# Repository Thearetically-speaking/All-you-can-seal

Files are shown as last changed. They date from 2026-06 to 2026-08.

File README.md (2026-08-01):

# All You Can SEAL

> Modify Bambu Lab 3D printers into a TPU heat-sealing tool by patching G-code.

This project rewrites the G-code inside Bambu Studio's `.gcode` and `.gcode.3mf` files to repurpose any Bambu printer (tested on **A1 mini** and **P1S**) as a heat-sealing machine. Instead of extruding filament to build a 3D object, the modified printer traces a 2D path with the nozzle hovering just above the bed — fusing two layers of TPU film into a custom-shaped inflatable pouch.

## What it does
 
Soft pneumatic wearables need airtight TPU chambers, and making them has traditionally required an impulse sealer, an ultrasonic welder, or a custom CNC sealing platform. This method produces them on a stock consumer 3D printer.
 
Heat sealing needs three inputs — **heat, contact pressure, and dwell time**. All three are recovered from parameters the printer already has:
 
| Input | How it's delivered |
|---|---|
| **Heat** | Raised nozzle temperature |
| **Pressure** | A negative Z offset presses the nozzle into the film stack, with the force distributed by a bead of over-extruded molten TPU |
| **Dwell time** | A heavily reduced feed rate |
 
**Extrusion stays on — that's the point.** Prior 3D-printer sealing methods disable extrusion and use the bare nozzle as a passive heat source, which lets residue build up and wears the nozzle. Here the deposited bead acts as a continuously refreshed interface between nozzle and film: it transmits heat and pressure into the stack while lubricating the nozzle so it doesn't drag on the release layer. The bead is part of the mechanism, not a by-product.
 
Nothing is modified or sacrificed. Only the parchment release layer is consumed per seal, and the printer goes back to normal printing immediately afterwards.
 
---
 
## Two ways to use it
 
### 🛜 Web app (recommended)
 
<https://thearetically-speaking.github.io/All-you-can-seal/>
 
1. **Convert** — drop in a `.gcode.3mf` exported by Bambu Studio (or a bare `.gcode`), pick your film thickness, download the patched file.
2. **Validate** — check a patched file before you send it to the printer. Worth doing every time; this workflow drives the nozzle *below* the bed's zero point.
Available in English and 中文. All processing happens client-side.
 
### 🐍 Python script
 
```bash
git clone https://github.com/Thearetically-speaking/All-you-can-seal.git
cd All-you-can-seal
python3 allyoucanseal-bambu.py path/to/your_sliced_file.gcode.3mf
```
 
Python 3.10+, standard library only. The script edits the file in place and writes two copies alongside it for diffing:
 
```
your_file.before.gcode    # original
your_file.after.gcode     # patched
your_file.gcode.3mf       # patched, ready to send
```
 
It works by treating the `.gcode.3mf` as the ZIP archive it is, locating `Metadata/plate_1.gcode`, patching both the config header and the machine body, and repacking.
 
---
 
## Parameters
 
**Verified on 0.03 mm and 0.05 mm TPU film**, across the **A1 mini**, **A1**, and **P1S**. For each thickness a single parameter set transfers across all three printers with no per-device tuning. Everything below is measured, not extrapolated — see [Other films](#other-films) for what is and isn't expected to carry over.
 
| Parameter | Stock | 0.03 mm film | 0.05 mm film | Role |
|---|---|---|---|---|
| Nozzle temperature | 230 °C | **250 °C** | **260 °C** | Heat |
| Z offset | 0 mm | −0.10 mm | −0.15 mm | Pressure |
| Extrusion multiplier | 100 % | 120 % | 120 % | Bead |
| Feed rate | 30 000 mm/min | **300 mm/min** | **180 mm/min** | Dwell |
 
Only the two thermal parameters change with thickness — heat delivery has to scale with the film's thermal mass. The pressure parameters hold constant across the tested range.
 
**Minimum reliable seam width: 2 mm**, at both thicknesses. Below that (tested at 1 mm) seals show occasional unbonded segments. The limit appears to be set by nozzle diameter and bead width rather than by the film.
 
---
 
## Other films
 
**The workflow is material-agnostic. The parameters are not.**
 
The stack-up, the slicer integration, and the patching script make no assumptions about what's being sealed — they only control heat, pressure and dwell. Any thin thermoplastic film that can be heat-sealed should be sealable this way. What has to be re-found for a new material is the *values*.
 
Splitting the four parameters by how far they're expected to travel:
 
| | Expected to transfer | Why |
|---|---|---|
| **Z offset**, **extrusion multiplier** | Likely, within a similar thickness range | These deliver mechanical contact pressure, and they held constant across our two thicknesses — the mechanism looks thickness-independent in the tested range |
| **Nozzle temperature**, **feed rate** | **No — must be re-tuned** | These deliver heat, which has to scale with the melting point and thermal mass of the specific film |
 
So a reasonable starting point for a new material: keep Z offset and extrusion multiplier, and search temperature and feed rate. Change one at a time. Prior work characterizing household thermoplastic films on stock FDM printers ([Therms-Up!](https://doi.org/10.1145/3430524.3442457)) is a useful reference for where different materials sit.
 
PVC and EVA are the obvious next candidates and are named as future work in the paper — **but read the safety note on PVC below before you try it.**
 
If you characterize a film we haven't, please open an issue with your parameters, film thickness and printer. A community-contributed table mapping film properties to parameter values is exactly what this needs.
 
---
 
## Hardware and materials
 
| Item | Notes |
|---|---|
| **Bambu Lab printer** | Verified on A1 mini, A1, P1S. Other Bambu models sharing the same G-code structure should work but are untested |
| **TPU film** | The material being sealed. Two layers. Characterized at 0.03 mm and 0.05 mm. Other thermoplastic films should work with re-tuned thermal parameters — see [Other films](#other-films) |
| **TPU filament** | Supplies the sealing bead. Generic Bambu TPU works |
| **Silicone mat, 2–3 mm** | Sits on the build plate. Absorbs the vertical contact force so the heated bed isn't indented and the nozzle never meets a rigid surface. **Not optional, and don't substitute cardboard** at these temperatures |
| **Parchment paper** | Release layer over the top of the stack. The bead adheres to the parchment, not to your film |
| **High-temperature tape** | Holds the stack at its edges. Kapton or equivalent — ordinary packing tape will not survive a 260 °C nozzle passing over it |
| **Spray bottle of water** | For misting between film layers |
 
---
 
## Material stack-up
 
Bottom to top:
 
1. Standard build plate
2. **2–3 mm silicone mat**
3. **Lower TPU film**, lightly misted with water — surface tension pulls it flat against the mat and eliminates trapped bubbles
4. **Upper TPU film**, again misted against the lower film so no air pocket remains between the two
5. **Parchment paper** covering the top, as the release layer
Tape the edges down with high-temperature tape so nothing shifts under nozzle motion.
 
The water misting is a functional step, not a nicety — trapped air between the layers produces unsealed segments.
 
---
 
## Full workflow
 
1. **Draw the seal path.** A closed 2D vector path (SVG). Keep the stroke ≥ 2 mm. Avoid sharp corners — the nozzle decelerates at corners and can scorch the film.
2. **Extrude to 0.28 mm** in Fusion 360 or any CAD tool, export STL. The 0.28 mm matches Bambu Studio's *Extra Draft* layer-height preset for a 0.4 mm nozzle, so the slicer emits exactly one layer of toolpath.
3. **Slice in Bambu Studio:** layer height 0.28 mm (Extra Draft), 1 layer, 1 wall, 100 % infill, no support, no brim. TPU filament profile, **bed temperature 30 °C**, **part cooling fan off** — active cooling stops the bead delivering sustained heat. Export as a **single-plate** slice file.
4. **Patch** with the web app or the script.
5. **Validate**, then dry-run with the heater off and watch the toolhead path before committing film.
6. **Seal.** Watch it.
---
 
## ⚠️ Safety
 
The printer is not permanently modified, but the process bypasses the slicer's safety checks. Read this before your first run.
 
- **The negative Z offset presses the nozzle below the bed's zero point.** Without the silicone mat you can scratch the build plate, damage the nozzle, or jam the toolhead.
- **250–260 °C is above the rated temperature of many TPU filaments.** Ventilate. Do not breathe the fumes.
- **Do not seal PVC or other chlorinated films without proper extraction.** PVC decomposes well below these temperatures and releases hydrogen chloride — corrosive to your lungs and to the printer. Room ventilation is not sufficient. This applies to any chlorine-containing film, including cling film and much craft vinyl. If you're exploring new materials, check the decomposition temperature and decomposition products *before* the melting point.
- **At 180–300 mm/min with the heater on, the nozzle dwells over every point.** Do not leave the printer unattended — if the toolhead stalls, the stack scorches within seconds.
- **Always dry-run first** with the heater off.
- Not endorsed by Bambu Lab. May void your warranty.
Intended for researchers, makers, and educators experimenting with soft fabrication. Not a product.
 
---
 
## Troubleshooting
 
**"Metadata/plate_1.gcode not found."** Your file was exported as multi-plate. In Bambu Studio use *Export single-plate slice file*.
 
**"CONFIG_BLOCK_END / MACHINE_START_GCODE_END not found."** The file wasn't sliced by Bambu Studio against a Bambu printer profile. Re-slice.
 
**Seal peels apart after cooling.** Not enough heat into the stack: raise temperature ~5 °C, or lower the feed rate. Change one variable at a time.
 
**Film scorches or browns.** Too much heat: drop the temperature first, then raise the Z offset toward zero. Confirm the parchment is between nozzle and film.
 
**Unsealed gaps along the path.** Seam width below 2 mm, trapped air between layers (mist more), or the stack shifted (more tape).
 
**Nozzle scrapes the bed.** Z offset too aggressive for your stack, or the silicone mat is too thin. Try −0.05 mm.
 
**Non-Bambu printer?** Not directly — the script targets Bambu's G-code dialect and the `.3mf` layout. Adapting it for Prusa or Klipper is feasible but unimplemented.
 
---
 
## Repository contents
 
| File | |
|---|---|
| `allyoucanseal-bambu.py` | The patching script |
| `test1.gcode.3mf` | Sample sliced file for testing the workflow |
| `TPU_Inflatable.pdf` | Reference seal patterns |
 
---
 
## Project context
 
Developed for **Catlike**, a Research-through-Design thesis on emotion-responsive pneumatic wearables at OCAD University — an HRV-responsive headpiece and a plantar-pressure-responsive shoe, both built on TPU bladders sealed in custom shapes.
 
The sealing method went through four stages: soldering iron → hair straightener → Cricut heat press → Bambu printer. Structures made with this workflow ran continuously in a four-day exhibition with no observed leakage.
 
If you use this for soft-robotics or wearable research, I'd like to hear about it.
 
## License
 
MIT.
 
You are free to share and adapt the material for non-commercial purposes, with attribution. Commercial use requires explicit permission.

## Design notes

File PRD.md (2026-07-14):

# PRD — All You Can Seal Web（网页版热封 G-code 处理器）

| | |
|---|---|
| 版本 | v0.1 草稿 |
| 日期 | 2026-07-12 |
| 现状 | 命令行脚本 `allyoucanseal-bambu.py`（Python，本地运行） |
| 目标形态 | 纯静态网页应用，托管于 GitHub Pages |

---

## 1. 背景与目标

现有的 Python 脚本可以把 Bambu Studio 切片产出的 `.gcode.3mf` 改写为 TPU 热封 G-code（改温度、Z 偏移、流量倍率、移动速度）。但它有明显的使用门槛和已知缺陷：

- 需要本地安装 Python，命令行操作，对非技术用户不友好；
- 改写结果不可见——用户无法在打印前直观确认路径和参数是否正确；
- 源打印温度 230°C 被硬编码，切片档位不是 230 时静默失败；
- 不更新 3mf 内的 `Metadata/plate_1.gcode.md5`，改写后校验和失效；
- 只支持单盘（`plate_1.gcode` 写死），多盘文件直接报错；
- 结构标记缺失时"改一半"而不是中止，可能产出危险的半成品文件。

**目标**：做一个零安装、拖拽即用的网页工具，覆盖并修复以上全部问题，让用户从"切片完成"到"拿到可打印的热封 3mf"在浏览器内一站完成，且在导出前能像切片软件一样预览整个热封路径。

**非目标（Out of Scope）**：
- 不做切片功能——用户仍需用 Bambu Studio 产出 `.gcode.3mf`；
- 不做非 Bambu 方言（Prusa/Klipper）的支持（架构上预留扩展点即可）;
- 不做打印机直连（LAN/云端发送）；
- 不做账号系统、云存储——文件全程只存在于用户浏览器内存中。

---

## 2. 用户与使用场景

**目标用户**：软体机器人 / 可穿戴研究者、maker、教育者。会用 Bambu Studio 切片，但不一定会命令行。

**核心使用流程（Happy Path）**：

1. 打开网页（GitHub Pages URL）；
2. 把 Bambu Studio 导出的 `.gcode.3mf` 拖进页面；
3. 网页自动解析：识别机型、检出切片温度、列出盘（plate）；
4. 用户在参数面板确认/调整四个热封参数（默认值即当前脚本常量）；
5. 3D 预览区显示改写后的完整路径，拖动 slider 逐步查看喷嘴行进过程；
6. 安全检查面板全绿（或用户确认警告）后，点击导出；
7. 浏览器下载改写后的 `.gcode.3mf`，用户发送到打印机。

---

## 3. 功能需求

### FR-1 文件导入（拖拽 + 点击选择）

- 支持拖拽（drag & drop）和点击文件选择两种方式；接受 `.gcode.3mf` 和裸 `.gcode`。
- 导入后立即在浏览器内解包（3mf 即 zip），**文件不上传到任何服务器**，页面上明确标注这一点（隐私是卖点）。
- 解析失败（非 zip、找不到 gcode、非 Bambu 结构）给出具体、可操作的错误提示（如"该文件缺少 CONFIG_BLOCK_END 标记，请确认使用 Bambu Studio 切片并选择 Bambu 打印机档位"）。
- 显示文件基本信息：文件名、机型（从 `;===== machine:` 头解析）、盘数、每盘的层数与预计路径长度、切片时的喷嘴温度。

### FR-2 多盘（multi-plate）处理

- 枚举 3mf 内所有 `Metadata/plate_N.gcode`（不再写死 `plate_1`）。
- 单盘文件：自动选中，无额外交互。
- 多盘文件：显示盘列表（含 3mf 自带的 `plate_N.png` 缩略图），用户可：
  - 选择其中一盘或多盘进行改写（未选中的盘原样保留）；
  - 或"全部改写"。
- 导出时对每个被改写的盘同步更新其对应的 `plate_N.gcode.md5`。

### FR-3 参数面板（可调，默认值沿用现脚本）

| 参数 | 默认值 | 允许范围（硬限制） | 说明 |
|---|---|---|---|
| 喷嘴温度 | 260°C | 180–300°C（按机型上限进一步收紧） | 热封温度 |
| Z 偏移 | −0.15 mm | −0.30 – +0.10 mm | 负值 = 压入膜面 |
| 流量倍率 | 120% | 50–200% | 注入 `M221` |
| 移动速度 | 5 mm/s | 1–30 mm/s | 主体所有独立 `G1 F` 行 |

- 每个参数带滑块 + 数字输入双控件，附一句"这个参数干什么用"的说明和调参方向提示（沿用 README 的 troubleshooting 经验，如"封不牢→温度 +5°C 或 Z 再压低"）。
- 超出允许范围直接阻止输入；接近危险边界（如 Z < −0.20）时显示黄色警告但允许继续。
- 提供"恢复默认"按钮。
- 参数记忆：用 localStorage 记住用户上次的参数（可选、可清除）。

### FR-4 G-code 改写引擎（Python 脚本逻辑的移植 + 修复）

将现有脚本的四类改写移植为 TypeScript 模块，并修复已知问题：

1. **喷嘴温度（修复硬编码，见 FR-8）**：改写开机段中等于"源打印温度"的 `M104/M109 S<t>` 行 → 目标温度；同步改配置头 `nozzle_temperature`、`nozzle_temperature_initial_layer`。开机段固定流程温度（170/140/250 等预热、擦嘴温度）不动。
2. **Z 偏移**：改写 `G29.1 Z… ; for Textured PEI Plate` 行。若找不到该行（非 Textured PEI 床型），列入安全检查警告并说明后果，而不是静默跳过。
3. **流量倍率**：在打印主体 `;VT0` 后注入/替换 `M221 S<flow>`；同步改配置头 `filament_flow_ratio`。
4. **移动速度**：主体内独立 `G1 F<n>` 行 → `G1 F<speed×60>`；行内 `F30000` token → 同值替换。
5. **改写标记**：在 gcode 头部注入一行处理标记（如 `; allyoucanseal: processed v<version> params=<json>`），用于防重复处理（FR-6）和溯源。
6. **md5 同步**：改写后重算并更新 3mf 内对应的 `.gcode.md5` 文件（当前脚本的已知缺陷）。
7. 引擎必须是纯函数式的（输入文本+参数 → 输出文本+变更报告），与 UI 解耦，便于单元测试。

### FR-5 3D 路径预览（核心功能）

类似切片软件的预览体验：

- **渲染内容**：解析改写后主体段的 G0/G1/G2/G3 移动，在 3D 场景中绘制路径折线，叠加打印床（按机型尺寸，A1 mini 180×180 / P1S 256×256）。
- **着色**：至少两种模式——
  - 按移动类型：热封线（挤出移动）vs 空驶（travel，非挤出），空驶用半透明细线；
  - 按速度：色带映射 feedrate，用于确认"主体真的全变成 5 mm/s 了"。
- **步进 slider（核心交互）**：
  - 拖动 slider 从第 0 步到最后一步，路径逐段显示，模拟喷嘴行进；
  - 当前位置显示喷嘴标记（小圆锥/点），旁边浮层显示该步的 X/Y/Z、速度、是否挤出、所在层；
  - 支持播放/暂停按钮（自动步进）和步进速度调节；
  - 多层文件支持按层过滤（层 slider 或下拉，类似 Bambu Studio 的垂直层滑条）。
- **相机**：轨道控制（旋转/平移/缩放），提供俯视图快捷按钮（热封本质是 2D 路径，俯视是主要视角）。
- **对比模式（nice-to-have，P2）**：切换查看改写前/改写后的速度着色差异。
- **性能**：典型热封文件主体几千段移动，直接渲染即可；上限设计按 50 万段移动流畅（BufferGeometry + 增量绘制），解析放 Web Worker，不阻塞 UI。

### FR-6 安全检查（导出前门禁）

导出按钮前置一个检查清单面板，逐项显示 ✅/⚠️/❌：

**硬性检查（❌ 阻止导出，除非用户勾选"我了解风险"强制导出）：**
- 三个结构标记（`CONFIG_BLOCK_END` / `MACHINE_START_GCODE_END` / `MACHINE_END_GCODE_START`）齐全——缺任一项则完全不改写，绝不产出半成品；
- 可执行段温度改写数 > 0（配置头计数与可执行行计数**分开显示**，杜绝现脚本"只改了注释也算成功"的误导）；
- `M221` 成功注入（找到 `;VT0`）；
- 改写后主体无残留高速独立 `G1 F` 行（反向断言）；
- 目标温度不超过该机型热端上限。

**警告级检查（⚠️ 提示但可导出）：**
- 检测到"已处理标记"——文件疑似被本工具或旧脚本处理过（防二次叠加）；
- 机型不在已验证列表（A1 mini、P1S）；
- 未找到 Textured PEI 的 `G29.1` 行（Z 偏移未生效，提示实际后果和替代做法）；
- Z 偏移低于 −0.20 mm；
- 检测到异常拼接行（如旧脚本损坏产生的 `M104 S260M140 S30` 类无换行行）。

每项检查带"这是什么、为什么重要"的展开说明。README 中现有的安全警告（垫硅胶垫、通风、不可离人、先空跑）在导出成功页显著展示一次。

### FR-7 导出

- 在浏览器内重打包 3mf：被改写的 `plate_N.gcode` 与对应 `.md5` 更新，其余 zip 条目字节级原样保留（缩略图、model、config 等）。
- 下载文件名：`<原名>-sealed.gcode.3mf`（不覆盖原文件语义，用户手里永远留有原件）。
- 提供"变更报告"视图：每类修改的实际改动数、旧值→新值（真实解析值，不是写死的展示文案）；可下载 before/after 纯文本 gcode 供 diff。
- 裸 `.gcode` 输入则导出改写后的 `.gcode`。

### FR-8 源温度自动识别（去除硬编码 230）

- 从配置头读取 `nozzle_temperature_initial_layer` / `nozzle_temperature` 作为"源打印温度"，用它（而非硬编码 230）匹配开机段的 `M104/M109` 行。
- 两个值不一致时分别按各自的值匹配替换。
- UI 上显示"检测到切片温度：230°C → 将改为 260°C"，用户可见、可核对。
- 极端情况（配置头缺失该键）：回退为让用户手动输入源温度，同时警告。
- 保留排他保护：等于固定流程温度（预热 170、擦嘴 140 等，按机型 start gcode 特征维护一个列表）的行永不改写，防止源温度恰好撞上流程温度时误伤。

---

## 4. 非功能需求

| 类别 | 要求 |
|---|---|
| 部署 | 纯静态站点，GitHub Actions 自动构建部署到 GitHub Pages；无后端、无 API、无遥测 |
| 隐私 | 文件全程在浏览器内存处理，不发出任何网络请求（除加载站点资源本身）；页面明示 |
| 浏览器 | 最新 Chrome / Edge / Firefox / Safari 桌面版；移动端只需只读预览可用，处理流程以桌面为主 |
| 性能 | 50 MB 的 3mf 从拖入到预览就绪 < 5 秒（解析在 Web Worker）；slider 拖动 60 fps |
| 国际化 | 中英双语（UI 文案抽离，右上角切换），默认跟随浏览器语言 |
| 可测试性 | 改写引擎 100% 纯函数 + 单测覆盖；用仓库的真实 3mf 建立回归 fixture（注意：现有 `test1.gcode.3mf` 已被旧脚本处理过且含损坏行，需重新切一个干净的测试文件，损坏文件可留作"已处理检测"的负例） |
| UI 风格 | 现代、简洁：单页三栏式布局（左：文件与参数，中：3D 预览，右：安全检查与导出）；深色模式支持；参考 Bambu Studio 预览页的视觉语言但不抄袭其品牌元素 |

---

## 5. 技术方案建议（供实现参考，非强制）

- **框架**：Vite + React + TypeScript（或 Svelte，团队熟悉为准）；
- **3D**：Three.js（`Line2`/`BufferGeometry` 增量绘制路径；OrbitControls）；
- **Zip**：`fflate`（轻量、支持流式）或 JSZip；md5 用 `spark-md5`；
- **G-code 解析**：自研轻量解析器（只需 G0/G1/G2/G3/M104/M109/M221 与注释标记，无需完整方言支持），运行在 Web Worker；
- **状态**：文件 → 解析结果 → 参数 → 改写结果 → 检查结果，单向数据流；参数变更即时重算改写与检查（改写引擎足够快，无需手动"应用"按钮）；
- **部署**：`gh-pages` 分支或 Actions `deploy-pages`，PR 预览可用 Actions artifact。

---

## 6. 里程碑建议

| 阶段 | 内容 | 验收 |
|---|---|---|
| M1 引擎移植 | TS 改写引擎 + 单测 + FR-8 动态温度 + md5 修复 | 对干净 fixture 的输出与预期逐行一致；旧脚本已知 bug 全部有对应回归测试 |
| M2 基础流程 | 拖拽导入 → 参数面板 → 安全检查 → 导出（无 3D） | 全流程可在 GitHub Pages 上跑通，含多盘 |
| M3 3D 预览 | 路径渲染 + 步进 slider + 着色模式 | 拖 slider 可复现喷嘴全程；速度着色可肉眼验证 5 mm/s |
| M4 打磨 | 双语、深色模式、移动端只读、对比模式 | — |

---

## 7. 开放问题

1. 多盘"全部改写"时参数是否允许每盘不同？（v1 建议：全局统一参数，简化 UI）
多盘的适合只改写第一盘
2. 是否需要在预览中估算总热封耗时（Σ 路径长度 ÷ 速度）并显示？（成本低、价值高，建议做）
可以
3. 机型热端温度上限表放哪维护？（建议：仓库内 JSON，社区可 PR 补充新机型）
json可以
4. 是否保留 Python 脚本作为 CLI 备选并与 TS 引擎共享测试 fixture？（建议保留，README 分别说明）
可以

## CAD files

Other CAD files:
test1.gcode.3mf

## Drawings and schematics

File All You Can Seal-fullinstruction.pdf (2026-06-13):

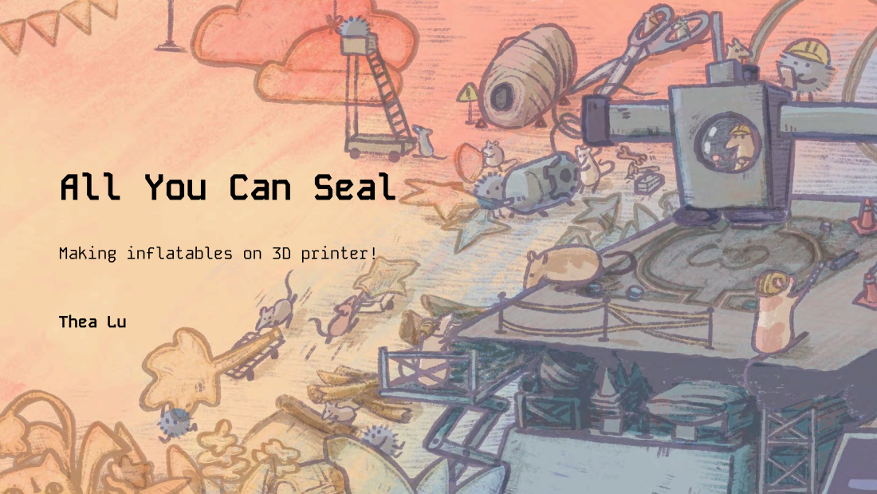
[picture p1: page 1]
Thea Lu

All You Can Seal

Making inflatables on 3D printer!

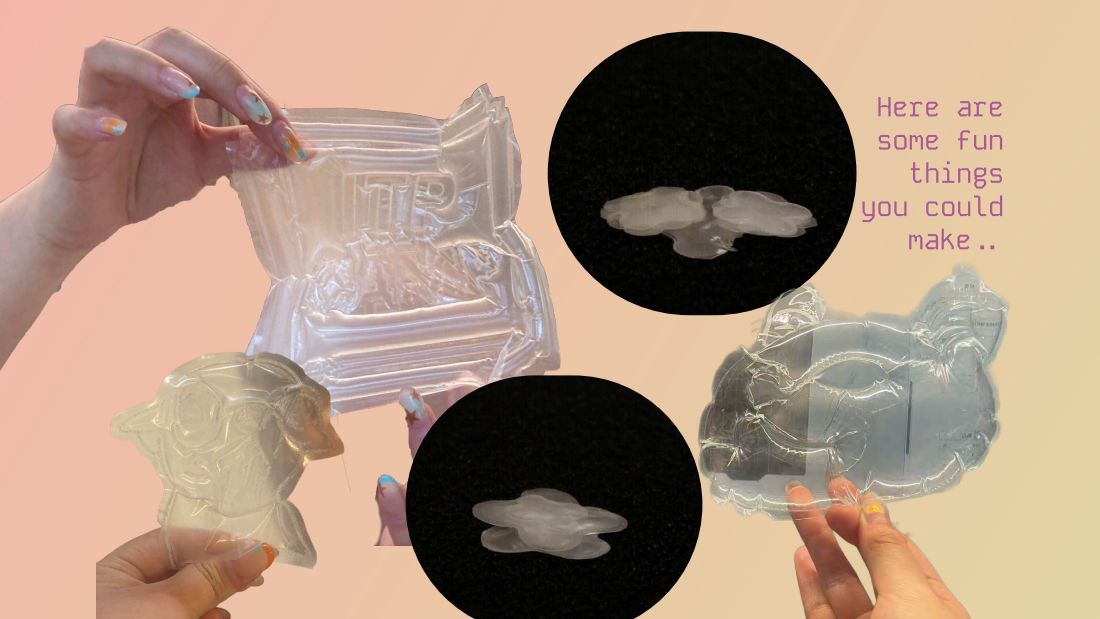
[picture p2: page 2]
Here are some fun things you could make..

What you need.....

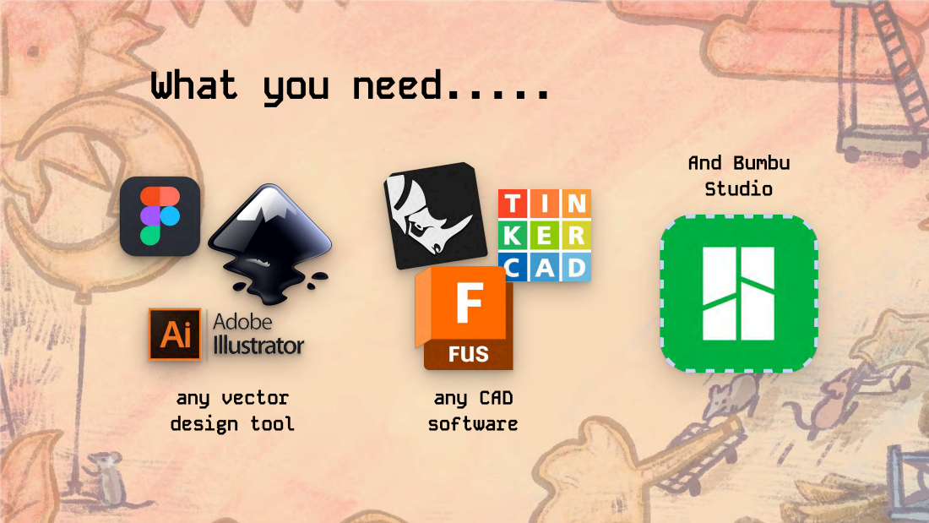
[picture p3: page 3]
And Bumbu Studio; any vector design tool; any CAD software

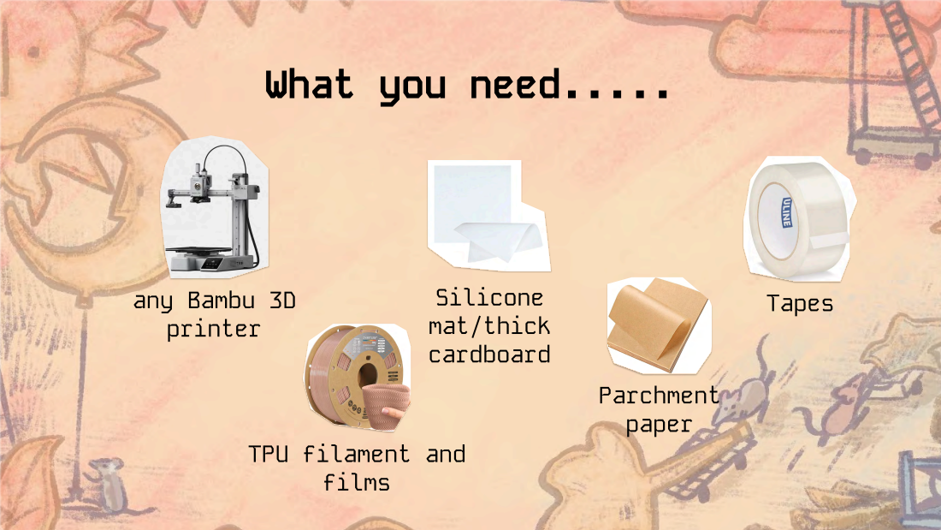
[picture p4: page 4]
Silicone mat/thick; cardboard; Parchment paper; any Bambu 3D printer; Tapes; films

What you need.....

TPU filament and

1

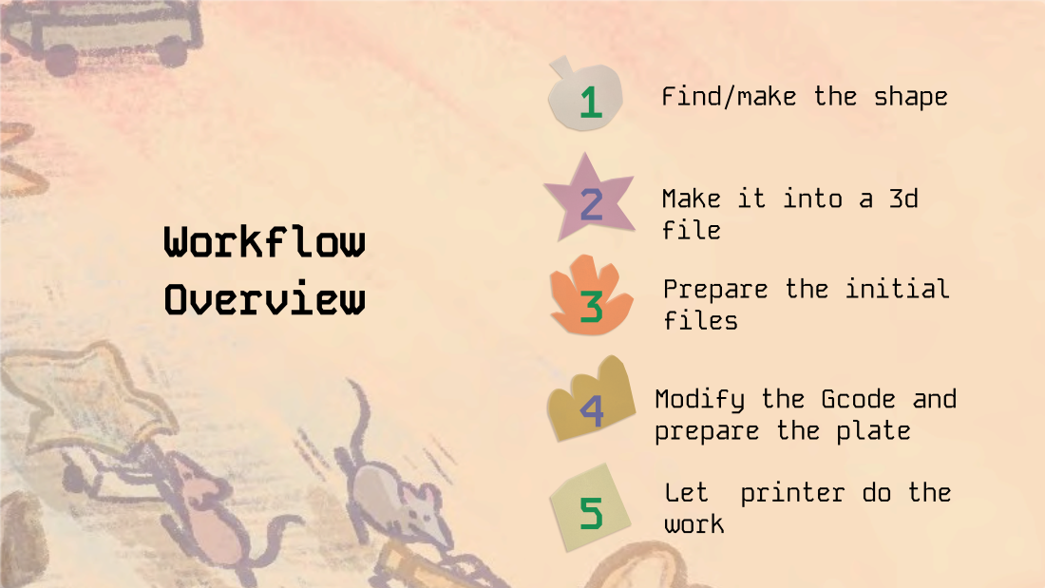
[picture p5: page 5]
Workflow Overview; Make it into a 3d file; Prepare the initial files; prepare the plate

Find/make the shape

Modify the Gcode and

Let printer do the
work

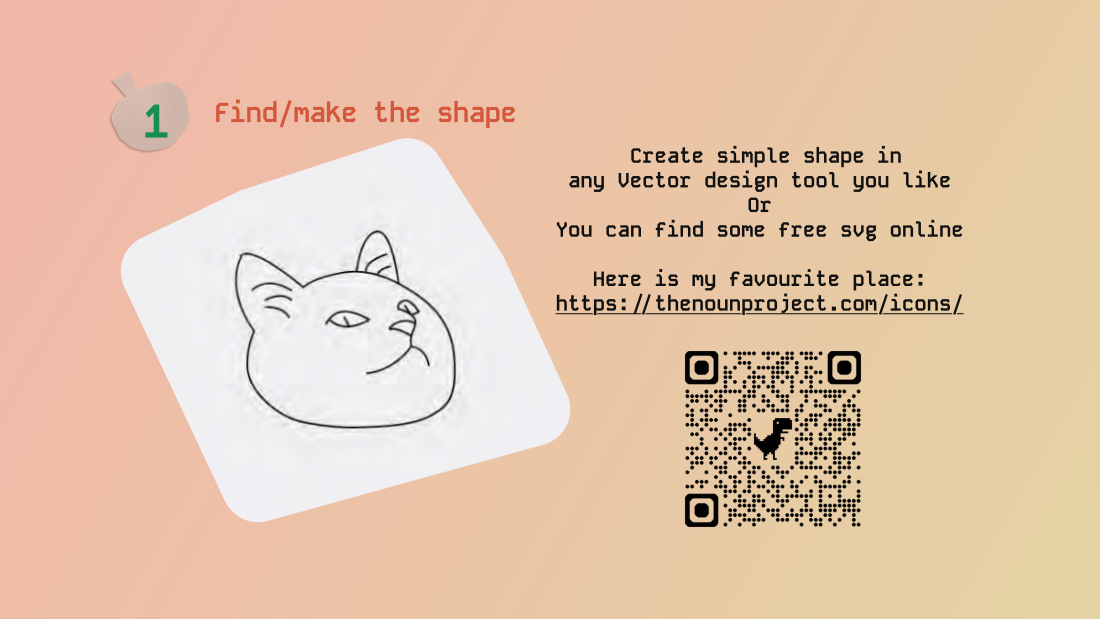
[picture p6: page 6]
Find/make the shape

Create simple shape in
any Vector design tool you like
You can find some free svg online
Here is my favourite place:
https://thenounproject.com/icons/

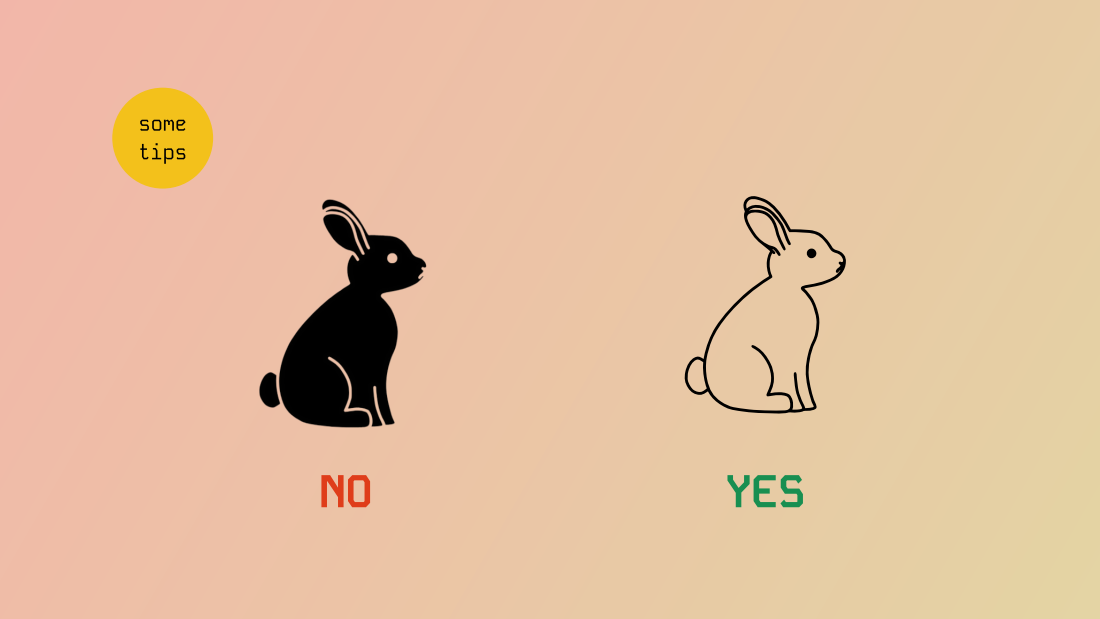
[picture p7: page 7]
some tips; YES

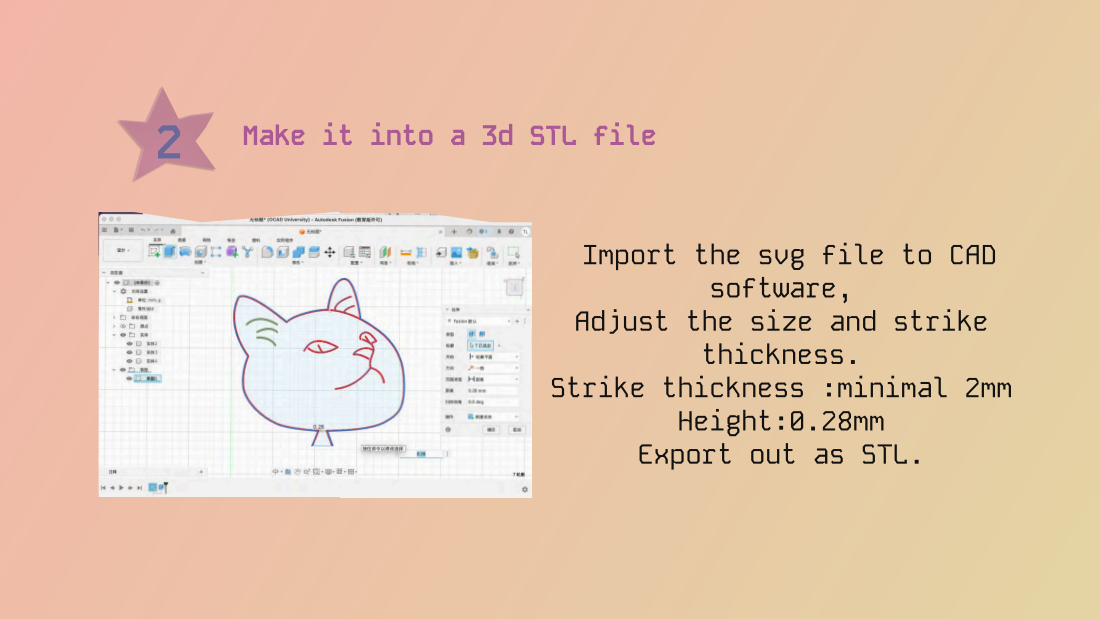
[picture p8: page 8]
Make it into a 3d STL file; software,; thickness.

Import the svg file to CAD

Adjust the size and strike

Strike thickness :minimal 2mm

Height:0.28mm
Export out as STL.

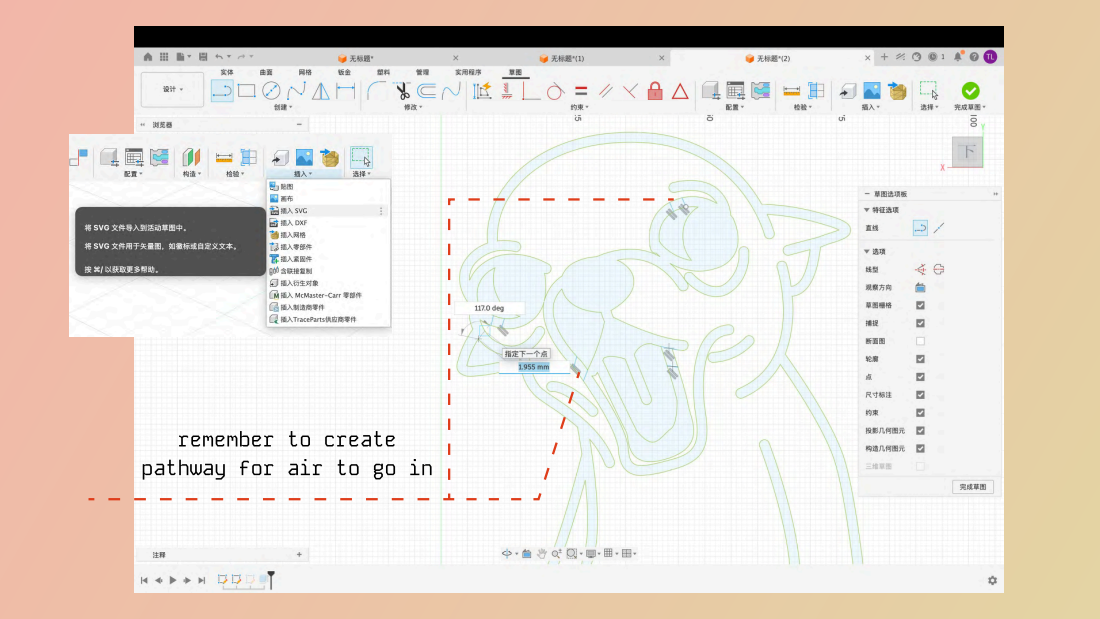
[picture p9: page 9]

remember to create
pathway for air to go in

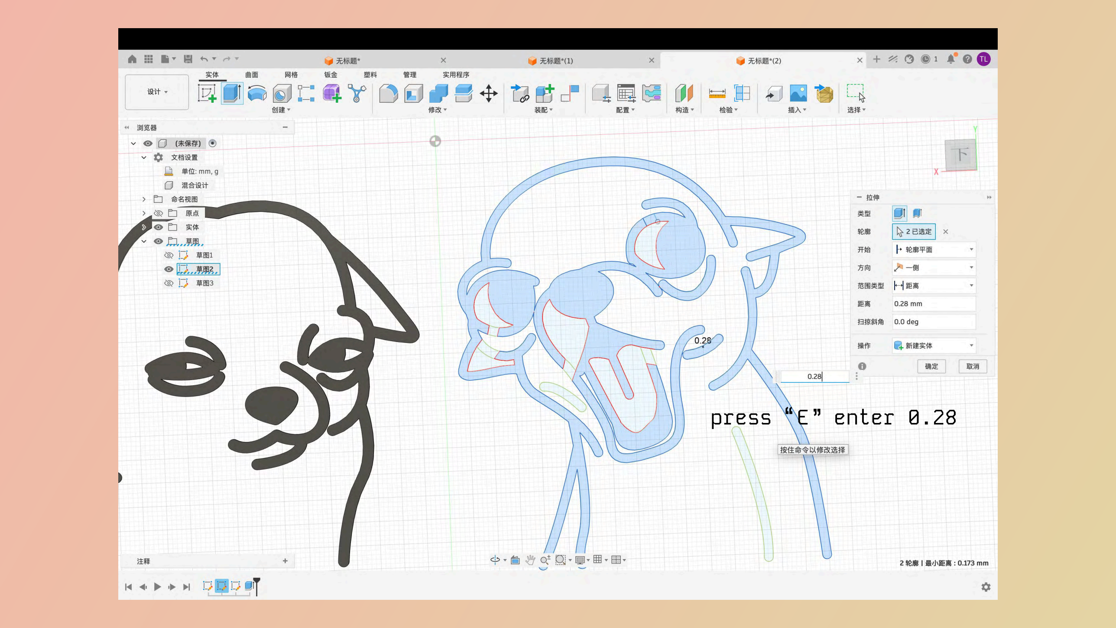
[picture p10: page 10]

press “E” enter 0.28

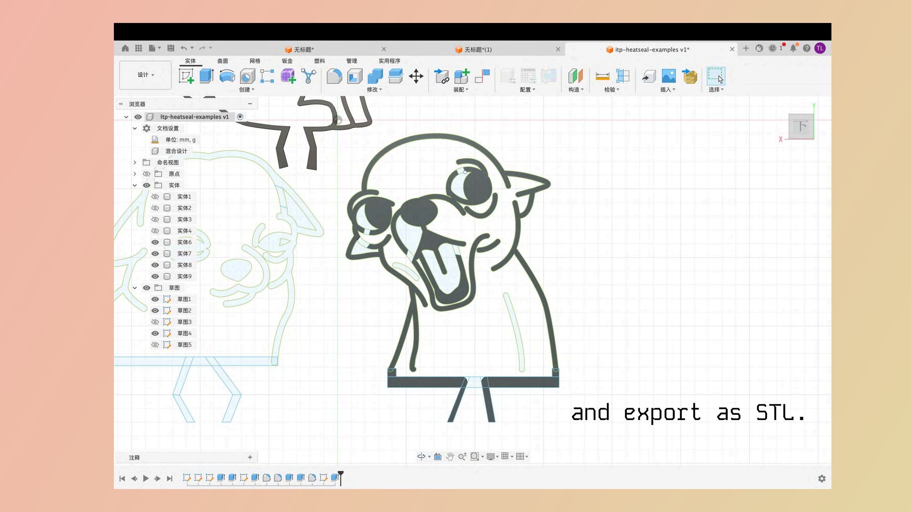
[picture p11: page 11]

and export as STL.

3

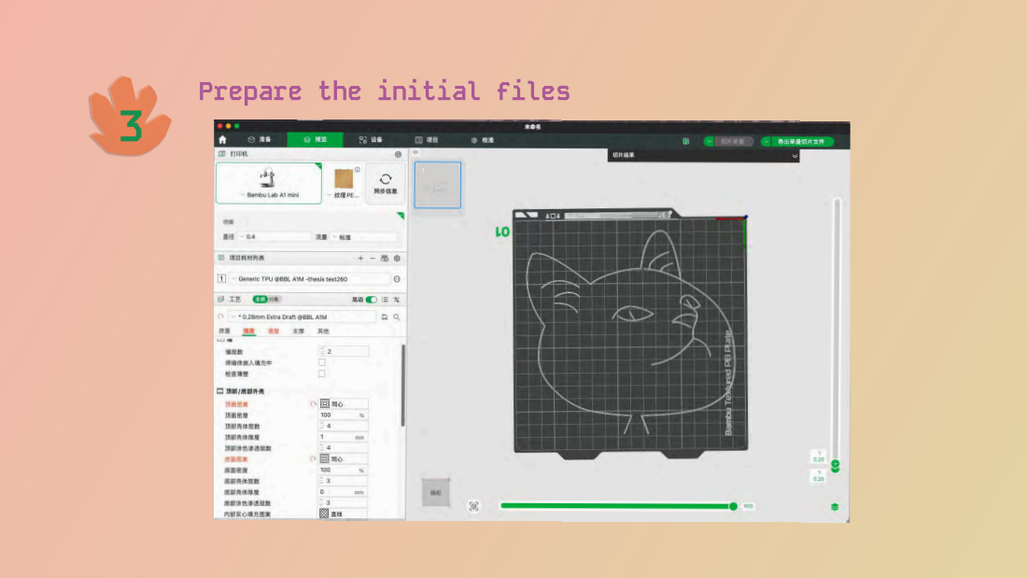
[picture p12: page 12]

Prepare the initial files


slice here

and export as
Export plate
sliced file


4 Modify the Gcode

How to fool Bambu....


Drag this to your Bambu studio and Let
the printer do the job!


How to Prepare the plate

## How to Prepare the plate

place the films; a silicone mat, aline them togather

spray water and

grab a plate and

Use a card to

remove any air 3


cut off the edge

and fold over,

use tape to secure

Make sure to be
bubble free

TaDa!!

Fold the parchment paper with a inch from the short side

cut off the edge

and fold over,

use tape to secure

## 5 Let printer do the work


# Play Time!!!

Group Up! 4-5 people a group; Prepare your Plate and Print

Make your design

And prepare your 3mf. file 2

（send your file to thealujx@gmail.com)

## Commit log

2026-06-13 Clarify flow rate purpose in README.md
    Updated flow rate explanation for M221 parameter.
2026-07-13 webpage hosting update, a pure web based solution for converting and processing 3mf to heat sealing
    [machines.json]
2026-08-01 Revise README for clarity and additional information
    Updated README.md to enhance project details, usage instructions, and safety warnings for using Bambu Lab 3D printers as TPU heat-sealing tools.
